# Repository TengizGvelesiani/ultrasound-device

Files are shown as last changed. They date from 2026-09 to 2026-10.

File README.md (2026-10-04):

# Portable Ultrasound System PCB

An open-source hardware and firmware project for a portable ultrasound system. This repository contains the schematic designs, PCB layouts, and FPGA-based digital signal processing infrastructure required to drive ultrasonic transducers, receive echoes, and process the resulting data.

## System Architecture

The architecture is divided into three main domains: the analog high-voltage front end, the FPGA-based digital signal processor (DSP), and the Python-based visualization software.

### Hardware & Analog Front End (AFE)
* **High-Voltage Pulser:** A high-voltage pulser circuit utilizing an **MD1213** high-speed dual-MOSFET driver paired with a **TC6320** complementary MOSFET pair. The FPGA generates highly precise transmit bursts (e.g., 3-cycle 5 MHz bursts) to ring the ultrasonic transducer.
* **Variable Gain Amplifier:** Features an **AD8331** Variable Gain Amplifier (VGA) optimized for ultrasound applications. The gain is dynamically driven by a hardware Time Gain Compensation (TGC) ramp using an **MCP4821** DAC to compensate for exponential acoustic attenuation in tissue.
* **Data Acquisition:** An **AD9226** Analog-to-Digital Converter (ADC) captures the amplified high-frequency RF signals at 20 MSPS.

### FPGA Digital Signal Processing (DSP)
The FPGA manages microsecond-precise transmit-receive (T/R) switching and processes the incoming 20 MHz data stream in real-time:
* **DC Blocking:** An Exponentially Weighted Moving Average (EWMA) high-pass filter actively tracks and rejects the ADC baseline DC offset.
* **Quadrature Demodulation:** Multiplier-less $f_s/4$ mixing (`[1, 0, -1, 0]`) brings the 5 MHz carrier frequency down to baseband.
* **Filtering & Magnitude:** FIR filters smooth the separated I and Q channels, and a hardware CORDIC calculates the exact signal magnitude ($\sqrt{I^2 + Q^2}$).
* **Log Compression:** To map the massive acoustic dynamic range to a visible spectrum, a BRAM-based Look-Up Table applies logarithmic compression before decimation.

### Software Stack & Visualization
* **High-Speed Telemetry:** The compressed ultrasound envelope is streamed over a 2,000,000 baud binary UART interface.
* **Python GUI:** A custom Python application reconstructs the data into a real-time medical-grade B-Scan waterfall using a `bone` colormap. The software applies customizable noise squelch (`NOISE_REJECT`) and contrast gain for optimal imaging of various targets.

## Repository Structure

* `/Pulser_PCB/` - Altium Designer project files (`.PrjPcb`), schematics (`.SchDoc`), and PCB layouts (`.PcbDoc`).
* `/FPGA/` - Vivado project and VHDL/Verilog source code for the FPGA, including the pulse controller and DSP pipelines.

## Getting Started

### Prerequisites
* **Altium Designer** for viewing, editing, and generating manufacturing files from the hardware project.
* **Xilinx Vivado (2018.3 or newer)** for synthesizing the digital logic.

### Viewing the Design
1. Clone this repository: `git clone https://github.com/TengizGvelesiani/ultrasound-device.git`
2. Open the hardware project file located in the `/Pulser_PCB/` directory using Altium Designer.
3. The top-level schematic outlines the power distribution, high-voltage pulser, and analog receive chain.

## Current Status & Roadmap

* [x] Initial schematic capture (Pulser, VGA, ADC)
* [x] PCB layout and routing
* [x] Board bring-up and power sequence testing
* [x] FPGA pulse generation and T/R switch timing verification (tuned for 5 MHz resonance)
* [x] Echo acquisition and DSP filtering (stable decimation, FIR, CORDIC)
* [x] Software visualization and UART pipeline integration
* [ ] Mechanical scanning and full 2D B-Scan implementation

## Disclaimer

**Educational and experimental purposes only.** This hardware generates high voltages and is not an approved medical device. It has not been evaluated by the FDA or any other regulatory body. Do not use this device on human subjects. The creators and contributors are not responsible for any damage, injury, or liability resulting from the use or misuse of this design. 

## License

This project is licensed under the [MIT License](LICENSE) - see the LICENSE file for details.

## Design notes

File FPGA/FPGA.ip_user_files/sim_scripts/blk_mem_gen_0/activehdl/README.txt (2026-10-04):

################################################################################
# Vivado (TM) v2018.3 (64-bit)
#
# README.txt: Please read the sections below to understand the steps required to
#             run the exported script and information about the source files.
#
# Generated by export_simulation on Sun Oct 04 17:19:32 +0400 2026
#
################################################################################

1. How to run the generated simulation script:-

From the shell prompt in the current directory, issue the following command:-

./blk_mem_gen_0.sh

This command will launch the 'compile', 'elaborate' and 'simulate' functions
implemented in the script file for the 3-step flow. These functions are called
from the main 'run' function in the script file.

The 'run' function first executes the 'setup' function, the purpose of which is to
create simulator specific setup files, create design library mappings and library
directories and copy 'glbl.v' from the Vivado software install location into the
current directory.

The 'setup' function is also used for removing the simulator generated data in
order to reset the current directory to the original state when export_simulation
was launched from Vivado. This generated data can be removed by specifying the
'-reset_run' switch to the './blk_mem_gen_0.sh' script.

./blk_mem_gen_0.sh -reset_run

To keep the generated data from the previous run but regenerate the setup files and
library directories, use the '-noclean_files' switch.

./blk_mem_gen_0.sh -noclean_files

For more information on the script, please type './blk_mem_gen_0.sh -help'.

2. Additional design information files:-

export_simulation generates following additional file that can be used for fetching
the design files information or for integrating with external custom scripts.

Name   : file_info.txt
Purpose: This file contains detail design file information based on the compile order
         when export_simulation was executed from Vivado. The file contains information
         about the file type, name, whether it is part of the IP, associated library
         and the file path information.

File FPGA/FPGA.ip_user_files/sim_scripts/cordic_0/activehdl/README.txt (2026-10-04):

################################################################################
# Vivado (TM) v2018.3 (64-bit)
#
# README.txt: Please read the sections below to understand the steps required to
#             run the exported script and information about the source files.
#
# Generated by export_simulation on Sun Oct 04 15:36:34 +0400 2026
#
################################################################################

1. How to run the generated simulation script:-

From the shell prompt in the current directory, issue the following command:-

./cordic_0.sh

This command will launch the 'compile', 'elaborate' and 'simulate' functions
implemented in the script file for the 3-step flow. These functions are called
from the main 'run' function in the script file.

The 'run' function first executes the 'setup' function, the purpose of which is to
create simulator specific setup files, create design library mappings and library
directories and copy 'glbl.v' from the Vivado software install location into the
current directory.

The 'setup' function is also used for removing the simulator generated data in
order to reset the current directory to the original state when export_simulation
was launched from Vivado. This generated data can be removed by specifying the
'-reset_run' switch to the './cordic_0.sh' script.

./cordic_0.sh -reset_run

To keep the generated data from the previous run but regenerate the setup files and
library directories, use the '-noclean_files' switch.

./cordic_0.sh -noclean_files

For more information on the script, please type './cordic_0.sh -help'.

2. Additional design information files:-

export_simulation generates following additional file that can be used for fetching
the design files information or for integrating with external custom scripts.

Name   : file_info.txt
Purpose: This file contains detail design file information based on the compile order
         when export_simulation was executed from Vivado. The file contains information
         about the file type, name, whether it is part of the IP, associated library
         and the file path information.

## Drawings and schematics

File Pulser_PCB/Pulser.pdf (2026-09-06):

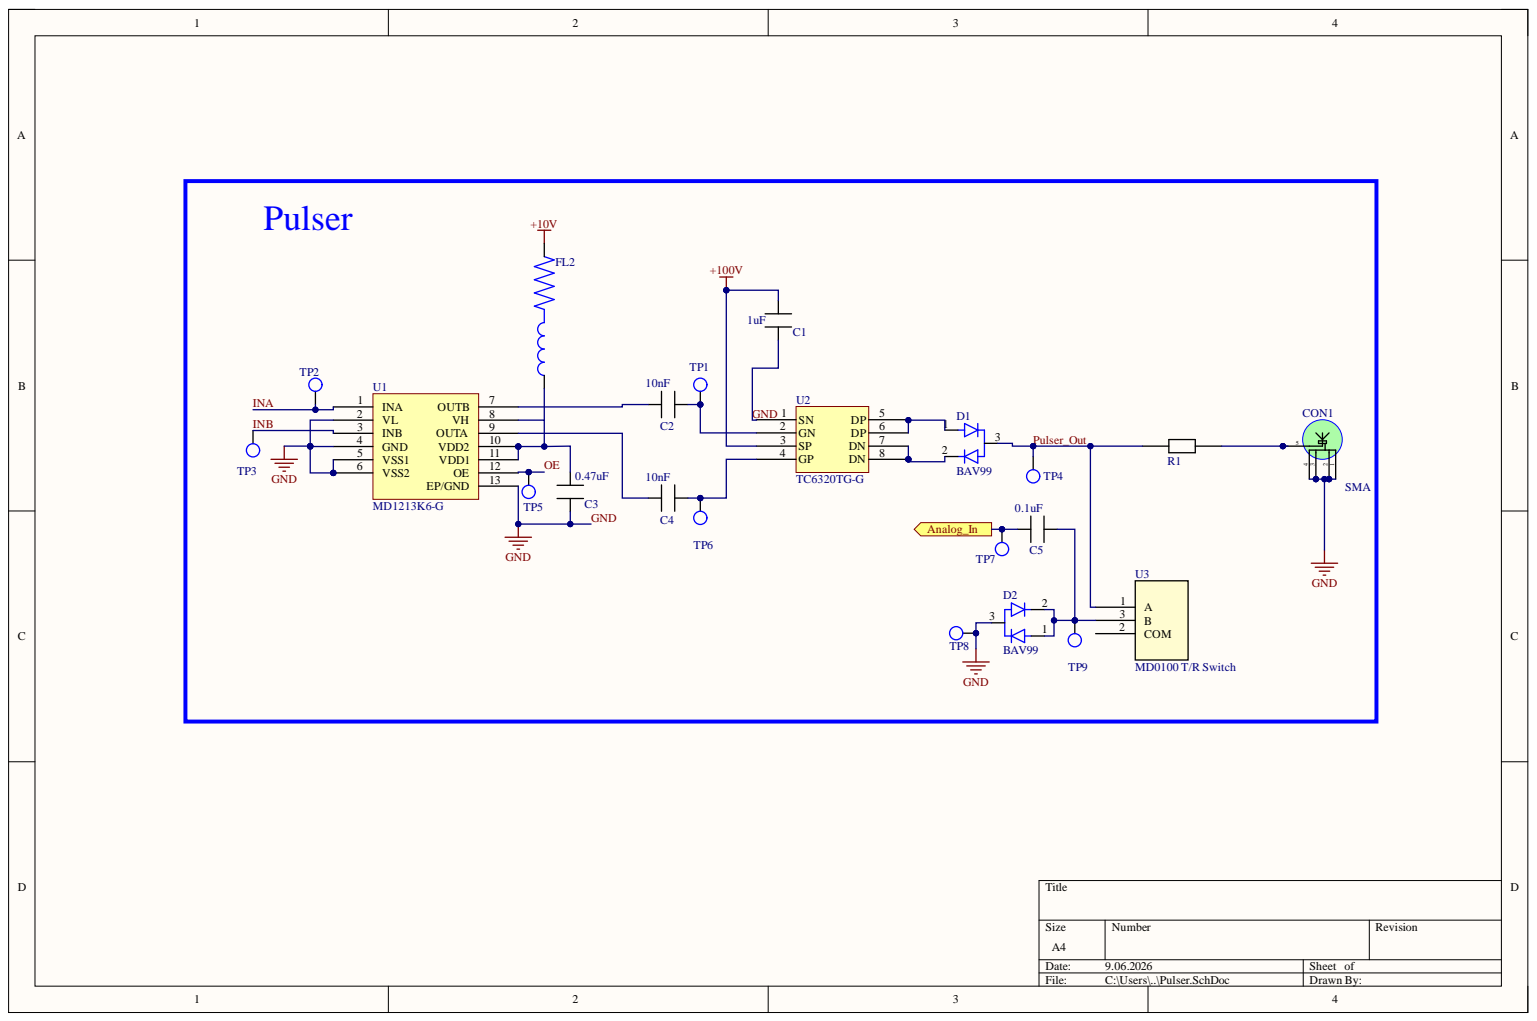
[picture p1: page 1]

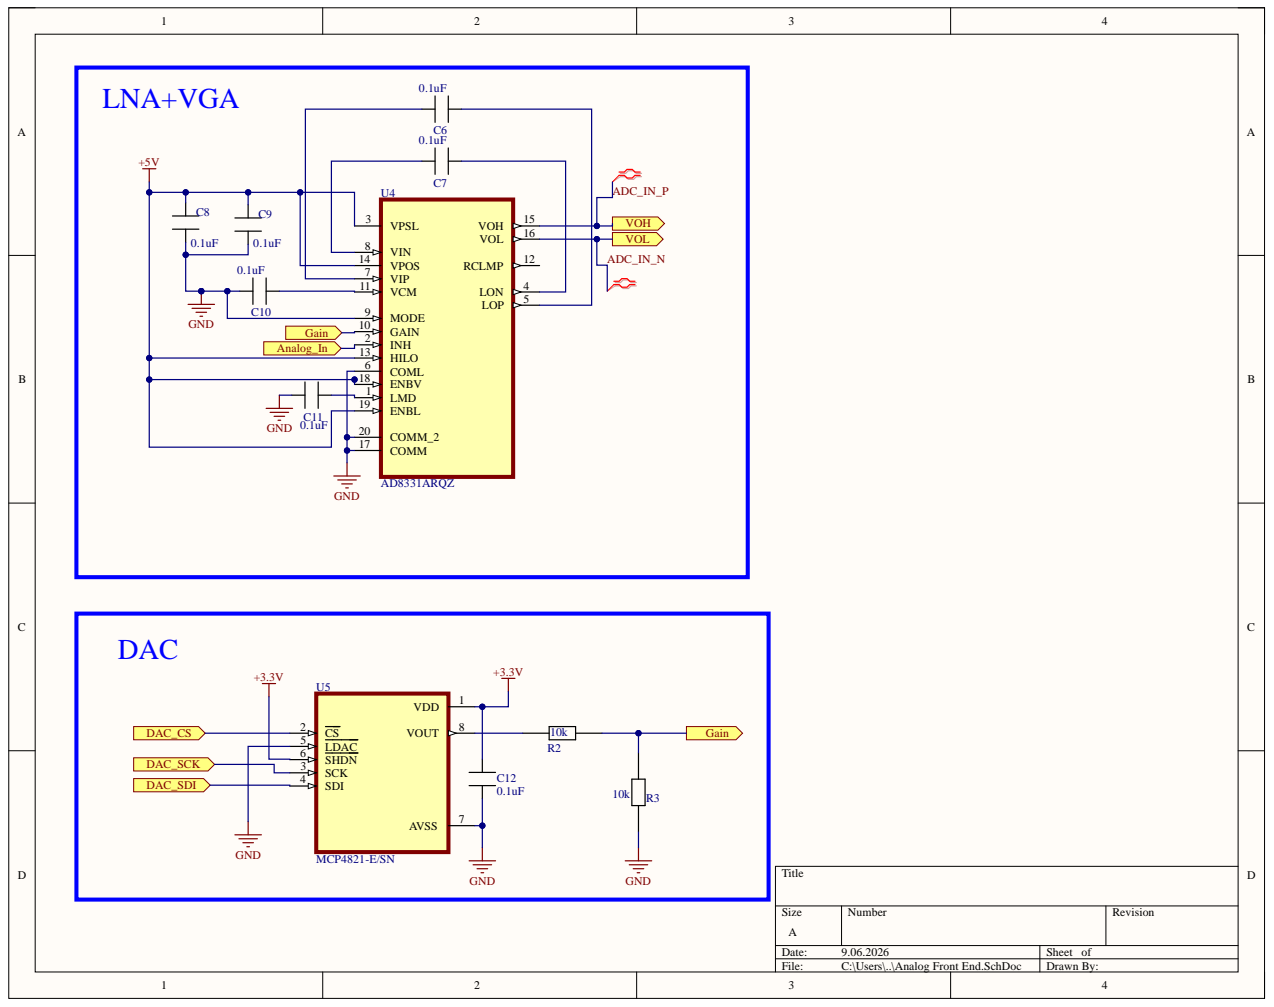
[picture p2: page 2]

ENBV 18

ENBL 19

SHDN 6

SDI 4

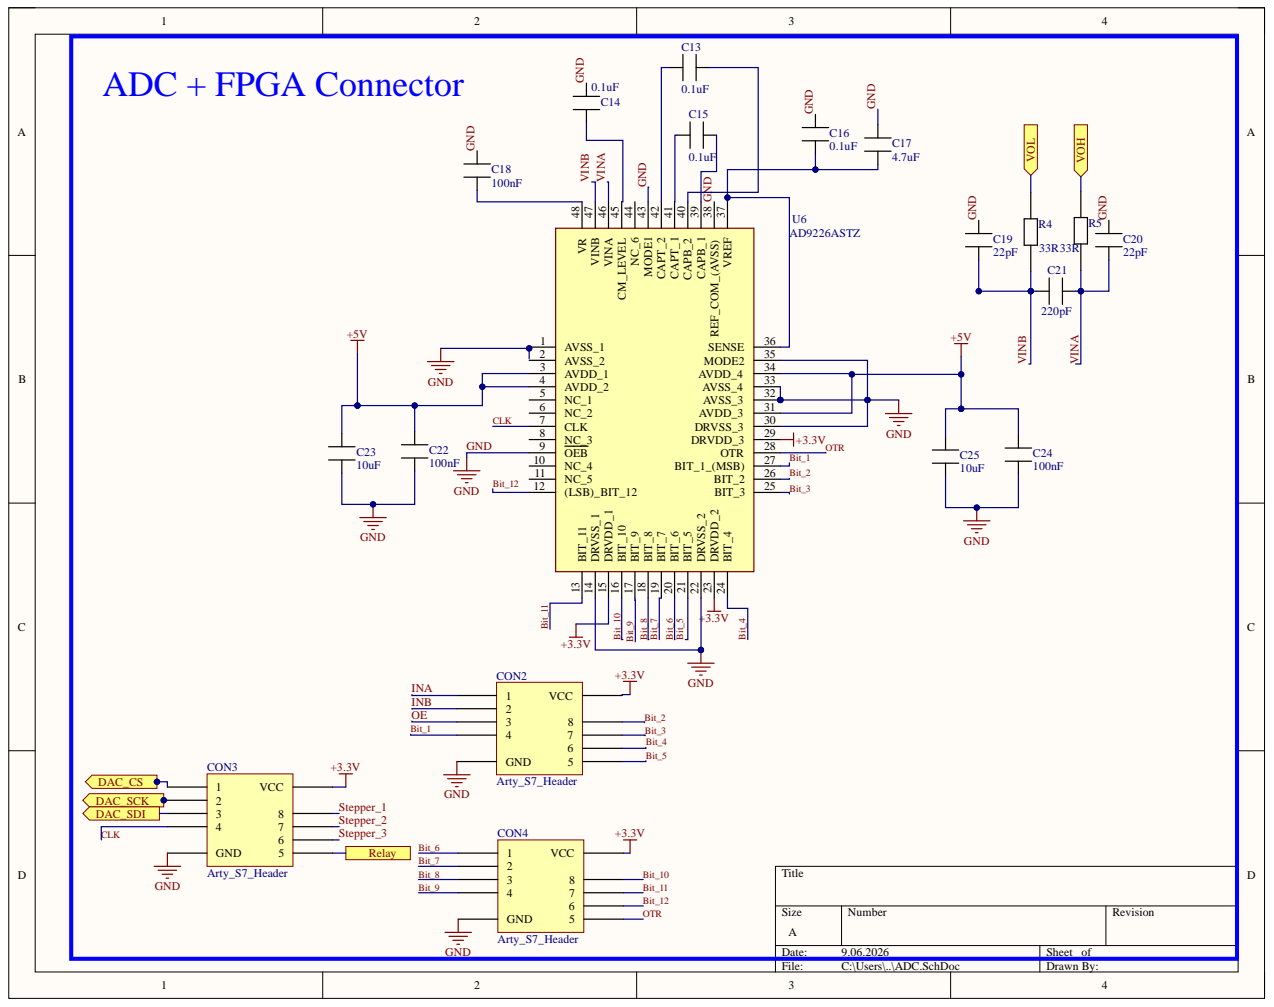
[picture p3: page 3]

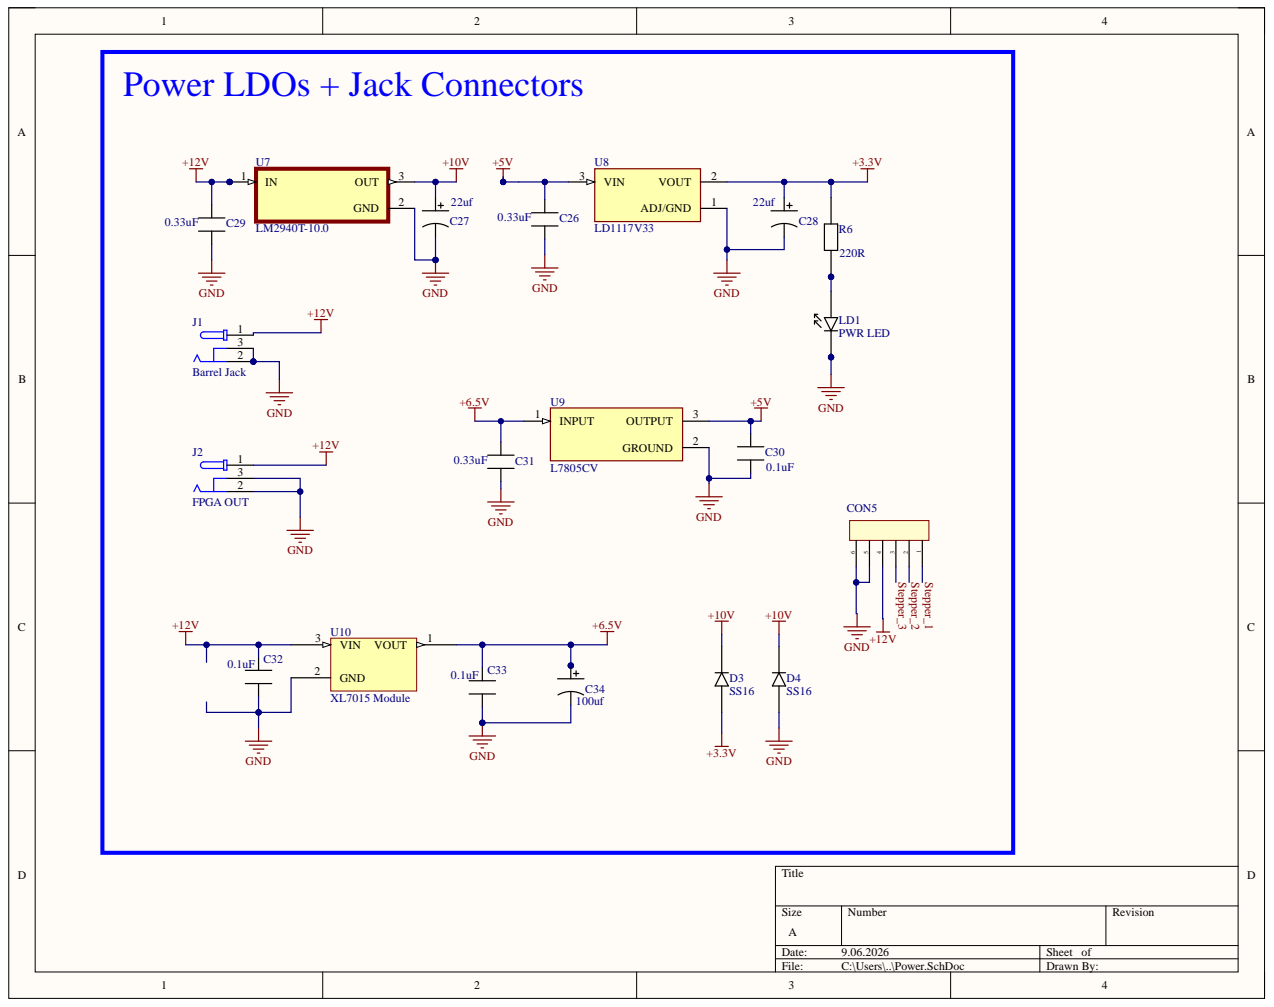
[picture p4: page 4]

Power LDOs + Jack Connectors

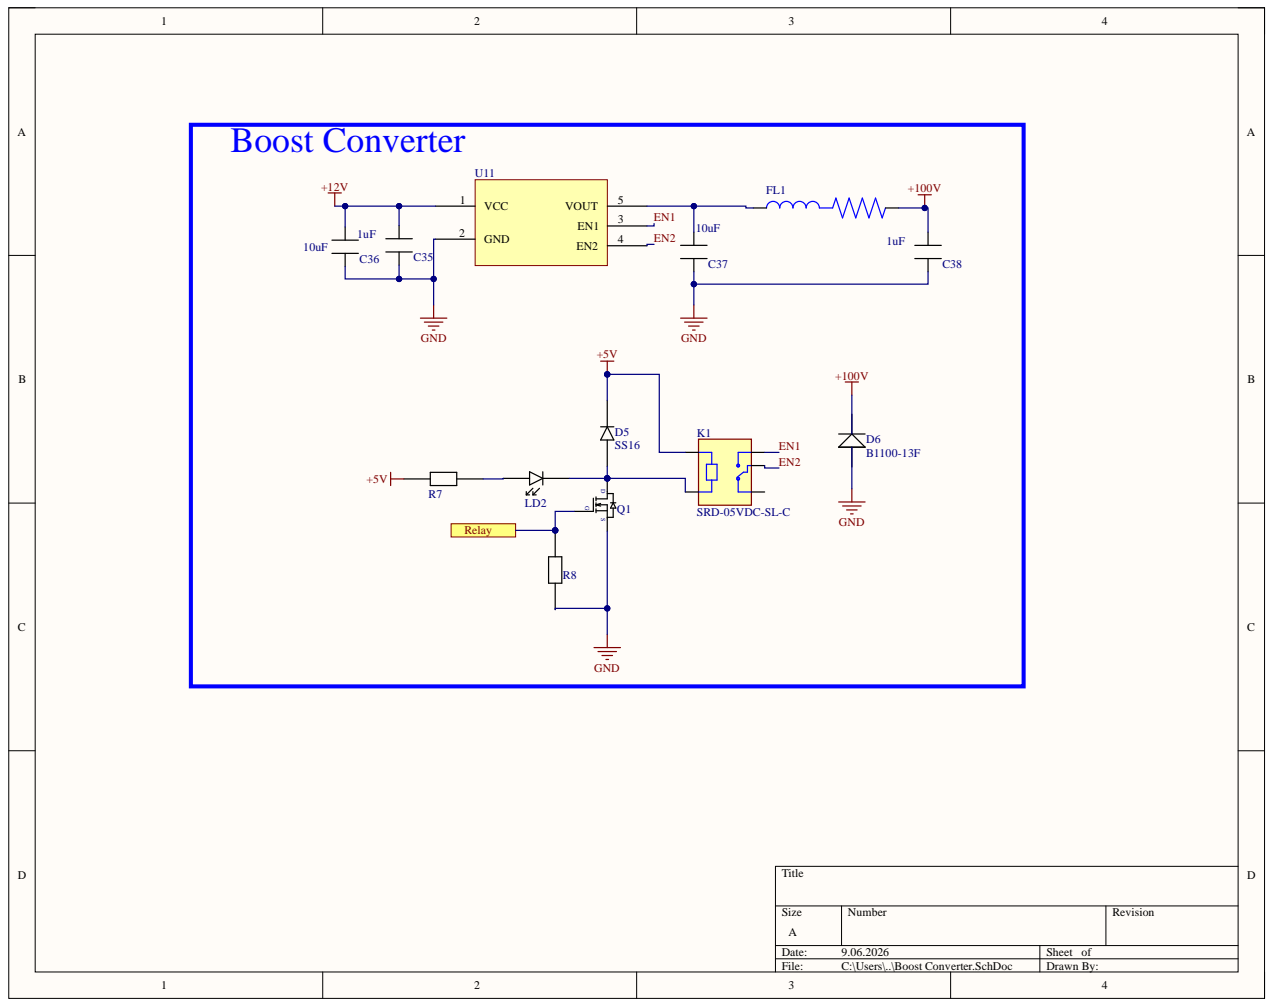
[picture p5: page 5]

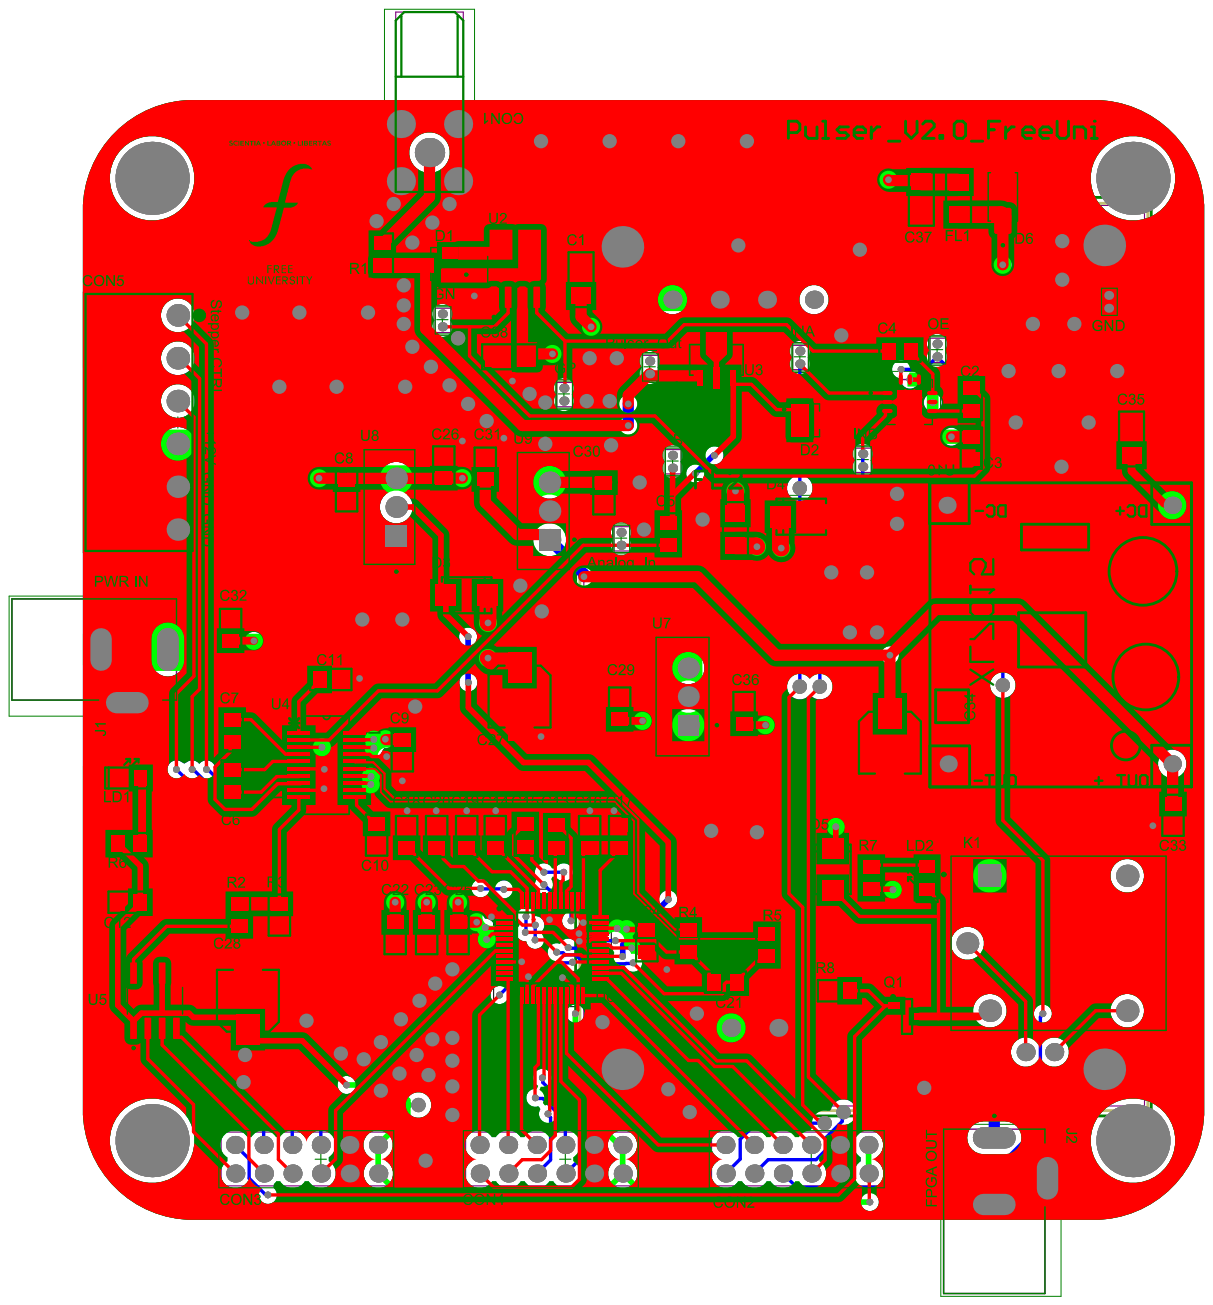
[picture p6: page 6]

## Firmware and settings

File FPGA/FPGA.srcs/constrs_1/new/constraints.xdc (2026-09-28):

## This file is a general .xdc for the Arty-S7 Rev. C
## To use it in a project:
## - uncomment the lines corresponding to used pins
## - rename the used ports (in each line, after get_ports) according to the top level signal names in the project

## Clock signal
#set_property -dict { PACKAGE_PIN F14   IOSTANDARD LVCMOS33 } [get_ports { CLK12MHZ }]; #IO_L13P_T2_MRCC_15 Sch=uclk
#create_clock -add -name sys_clk_pin -period 83.333 -waveform {0 41.667} [get_ports { CLK12MHZ }];
set_property -dict {PACKAGE_PIN R2 IOSTANDARD SSTL135} [get_ports CLK100MHZ]
create_clock -period 10.000 -name sys_clk_pin -waveform {0.000 5.000} -add [get_ports CLK100MHZ]

## Switches
#set_property -dict { PACKAGE_PIN H14   IOSTANDARD LVCMOS33 } [get_ports { sw[0] }]; #IO_L20N_T3_A19_15 Sch=sw[0]
#set_property -dict { PACKAGE_PIN H18   IOSTANDARD LVCMOS33 } [get_ports { sw[1] }]; #IO_L21P_T3_DQS_15 Sch=sw[1]
#set_property -dict { PACKAGE_PIN G18   IOSTANDARD LVCMOS33 } [get_ports { sw[2] }]; #IO_L21N_T3_DQS_A18_15 Sch=sw[2]
#set_property -dict { PACKAGE_PIN M5    IOSTANDARD SSTL135 } [get_ports { sw[3] }]; #IO_L6N_T0_VREF_34 Sch=sw[3]


## RGB LEDs
set_property -dict {PACKAGE_PIN J15 IOSTANDARD LVCMOS33} [get_ports {rgb_led[0]}]
set_property -dict {PACKAGE_PIN G17 IOSTANDARD LVCMOS33} [get_ports {rgb_led[1]}]
set_property -dict {PACKAGE_PIN F15 IOSTANDARD LVCMOS33} [get_ports {rgb_led[2]}]
set_property -dict {PACKAGE_PIN E15 IOSTANDARD LVCMOS33} [get_ports {rgb_led[3]}]
set_property -dict {PACKAGE_PIN F18 IOSTANDARD LVCMOS33} [get_ports {rgb_led[4]}]
set_property -dict {PACKAGE_PIN E14 IOSTANDARD LVCMOS33} [get_ports {rgb_led[5]}]


## LEDs
#set_property -dict { PACKAGE_PIN E18   IOSTANDARD LVCMOS33 } [get_ports { led[2] }]; #IO_L16N_T2_A27_15 Sch=led[2]
#set_property -dict { PACKAGE_PIN F13   IOSTANDARD LVCMOS33 } [get_ports { led[3] }]; #IO_L17P_T2_A26_15 Sch=led[3]
#set_property -dict { PACKAGE_PIN E13   IOSTANDARD LVCMOS33 } [get_ports { led[4] }]; #IO_L17N_T2_A25_15 Sch=led[4]
#set_property -dict { PACKAGE_PIN H15   IOSTANDARD LVCMOS33 } [get_ports { led[5] }]; #IO_L18P_T2_A24_15 Sch=led[5]


## Buttons
#set_property -dict { PACKAGE_PIN G15   IOSTANDARD LVCMOS33 } [get_ports { btn[0] }]; #IO_L18N_T2_A23_15 Sch=btn[0]
#set_property -dict { PACKAGE_PIN K16   IOSTANDARD LVCMOS33 } [get_ports { btn[1] }]; #IO_L19P_T3_A22_15 Sch=btn[1]
#set_property -dict { PACKAGE_PIN J16   IOSTANDARD LVCMOS33 } [get_ports { btn[2] }]; #IO_L19N_T3_A21_VREF_15 Sch=btn[2]
#set_property -dict { PACKAGE_PIN H13   IOSTANDARD LVCMOS33 } [get_ports { btn[3] }]; #IO_L20P_T3_A20_15 Sch=btn[3]


## PMOD Header JA (Relay, Stepper, DAC / ADC Clock)
set_property -dict { PACKAGE_PIN L17   IOSTANDARD LVCMOS33 } [get_ports { relay }];    # JA 1 (Pmod Pin 1)  - Relay
#set_property -dict { PACKAGE_PIN L18   IOSTANDARD LVCMOS33 } [get_ports { stepper3 }]; # JA 2 (Pmod Pin 2)  - Stepper3
#set_property -dict { PACKAGE_PIN M14   IOSTANDARD LVCMOS33 } [get_ports { stepper2 }]; # JA 3 (Pmod Pin 3)  - Stepper2
#set_property -dict { PACKAGE_PIN N14   IOSTANDARD LVCMOS33 } [get_ports { stepper1 }]; # JA 4 (Pmod Pin 4)  - Stepper1
set_property -dict { PACKAGE_PIN M16   IOSTANDARD LVCMOS33 } [get_ports { cs }];       # JA 5 (Pmod Pin 7)  - DAC_CS
set_property -dict { PACKAGE_PIN M17   IOSTANDARD LVCMOS33 } [get_ports { sck }];      # JA 6 (Pmod Pin 8)  - DAC_SCK
set_property -dict { PACKAGE_PIN M18   IOSTANDARD LVCMOS33 } [get_ports { sci }];      # JA 7 (Pmod Pin 9)  - DAC_SDI
set_property -dict { PACKAGE_PIN N18   IOSTANDARD LVCMOS33 } [get_ports { clk }];      # JA 8 (Pmod Pin 10) - ADC_CLK


## PMOD Header JB (OTR & Parallel ADC Upper Bits)
set_property -dict { PACKAGE_PIN P17   IOSTANDARD LVCMOS33 } [get_ports { otr }];          # JB 1 (Pmod Pin 1)  - OTR
set_property -dict { PACKAGE_PIN P18   IOSTANDARD LVCMOS33 } [get_ports { adc_data[12] }]; # JB 2 (Pmod Pin 2)  - ADC_BIT12
set_property -dict { PACKAGE_PIN R18   IOSTANDARD LVCMOS33 } [get_ports { adc_data[11] }]; # JB 3 (Pmod Pin 3)  - ADC_BIT11
set_property -dict { PACKAGE_PIN T18   IOSTANDARD LVCMOS33 } [get_ports { adc_data[10] }]; # JB 4 (Pmod Pin 4)  - ADC_BIT10
set_property -dict { PACKAGE_PIN P14   IOSTANDARD LVCMOS33 } [get_ports { adc_data[6] }];  # JB 5 (Pmod Pin 7)  - ADC_BIT6
set_property -dict { PACKAGE_PIN P15   IOSTANDARD LVCMOS33 } [get_ports { adc_data[7] }];  # JB 6 (Pmod Pin 8)  - ADC_BIT7
set_property -dict { PACKAGE_PIN N15   IOSTANDARD LVCMOS33 } [get_ports { adc_data[8] }];  # JB 7 (Pmod Pin 9)  - ADC_BIT8
set_property -dict { PACKAGE_PIN P16   IOSTANDARD LVCMOS33 } [get_ports { adc_data[9] }];  # JB 8 (Pmod Pin 10) - ADC_BIT9
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

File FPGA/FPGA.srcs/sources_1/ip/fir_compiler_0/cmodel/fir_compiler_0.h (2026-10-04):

//------------------------------------------------------------------------------
// (c) Copyright 2014 Xilinx, Inc. All rights reserved.
//
// This file contains confidential and proprietary information
// of Xilinx, Inc. and is protected under U.S. and
// international copyright and other intellectual property
// laws.
//
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
// CRITICAL APPLICATIONS
// Xilinx products are not designed or intended to be fail-
// safe, or for use in any application requiring fail-safe
// performance, such as life-support or safety devices or
// systems, Class III medical devices, nuclear facilities,
// applications related to the deployment of airbags, or any
// other applications that could lead to death, personal
// injury, or severe property or environmental damage
// (individually and collectively, "Critical
// Applications"). Customer assumes the sole risk and
// liability of any use of Xilinx products in Critical
// Applications, subject only to applicable laws and
// regulations governing limitations on product liability.
//
// THIS COPYRIGHT NOTICE AND DISCLAIMER MUST BE RETAINED AS
// PART OF THIS FILE AT ALL TIMES.
//------------------------------------------------------------------------------ 
//
// C Model configuration for the "fir_compiler_0" instance.
//
//------------------------------------------------------------------------------
//
// coefficients: -14,-24,-20,7,56,114,163,189,189,163,114,56,7,-20,-24,-14
// chanpats: 173
// name: fir_compiler_0
// filter_type: 0
// rate_change: 0
// interp_rate: 1
// decim_rate: 1
// zero_pack_factor: 1
// coeff_padding: 0
// num_coeffs: 16
// coeff_sets: 1
// reloadable: 0
// is_halfband: 0
// quantization: 0
// coeff_width: 16
// coeff_fract_width: 0
// chan_seq: 0
// num_channels: 1
// num_paths: 1
// data_width: 16
// data_fract_width: 0
// output_rounding_mode: 1
// output_width: 24
// output_fract_width: 0
// config_method: 0

const double fir_compiler_0_coefficients[16] = {-14,-24,-20,7,56,114,163,189,189,163,114,56,7,-20,-24,-14};

const xip_fir_v7_2_pattern fir_compiler_0_chanpats[1] = {P_BASIC};

static xip_fir_v7_2_config gen_fir_compiler_0_config() {
  xip_fir_v7_2_config config;
  config.name                = "fir_compiler_0";
  config.filter_type         = 0;
  config.rate_change         = XIP_FIR_INTEGER_RATE;
  config.interp_rate         = 1;
  config.decim_rate          = 1;
  config.zero_pack_factor    = 1;
  config.coeff               = &fir_compiler_0_coefficients[0];
  config.coeff_padding       = 0;
  config.num_coeffs          = 16;
  config.coeff_sets          = 1;
  config.reloadable          = 0;
  config.is_halfband         = 0;
  config.quantization        = XIP_FIR_INTEGER_COEFF;
  config.coeff_width         = 16;
  config.coeff_fract_width   = 0;
  config.chan_seq            = XIP_FIR_BASIC_CHAN_SEQ;
  config.num_channels        = 1;
  config.init_pattern        = fir_compiler_0_chanpats[0];
  config.num_paths           = 1;
  config.data_width          = 16;
  config.data_fract_width    = 0;
  config.output_rounding_mode= XIP_FIR_TRUNCATE_LSBS;
  config.output_width        = 24;
  config.output_fract_width  = 0,
  config.config_method       = XIP_FIR_CONFIG_SINGLE;
  return config;
}

const xip_fir_v7_2_config fir_compiler_0_config = gen_fir_compiler_0_config();

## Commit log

2026-03-17 pulser circuit finished
    [IC_Digital.PcbLib, IC_Digital.SchLib, MD1213K6-G.SchLib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]
2026-03-27 added schematics
    [ADC.SchDoc, Analog Front End.SchDoc, Connectors.PcbLib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]
2026-03-28 added power plug
    [Connectors.PcbLib, Connectors.SchLib, Power.SchDoc]
2026-03-28 add power schematics
    [ADC.SchDoc, Analog Front End.SchDoc, IC_Power.PcbLib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]
2026-03-29 changed bnc to sma connector
    [ADC.SchDoc, Analog Front End.SchDoc, Power.SchDoc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]
2026-03-30 first draft pcb layout
    [ADC.SchDoc, Analog Front End.SchDoc, Boost Converter.SchDoc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]
2026-03-30 updated gitignore
    [Pulser.PrjPcb]
2026-03-30 updated size
    [Boost Converter.SchDoc, IC_Power.PcbLib, Pulser.PcbDoc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]
2026-03-31 started routing
    [ADC.SchDoc, Analog Front End.SchDoc, Boost Converter.SchDoc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]
2026-03-31 finished pcb
    [Pulser.PcbDoc, Pulser.PrjPcb]
2026-03-31 finish pcb
    [Pulser.PrjPcb]
2026-03-31 change capacitor footprints
    [Boost Converter.SchDoc, Power.SchDoc, Pulser.PcbDoc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]
2026-04-01 final version
    [ADC.SchDoc, Boost Converter.SchDoc, Connectors.PcbLib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]
2026-09-04 updated connectors diodes
    [ADC.SchDoc, Boost Converter.SchDoc, Connectors.PcbLib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]
2026-09-04 add testpoints
    [ADC.SchDoc, Analog Front End.SchDoc, Boost Converter.SchDoc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]
2026-09-04 add test points
    [Pulser.SchDoc]
2026-09-04 small bug fix
    [ADC.SchDoc, Analog Front End.SchDoc, Boost Converter.SchDoc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]
2026-09-04 updated pcb layout
    [Boost Converter.SchDoc, Connectors.PcbLib, IC_Power.PcbLib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]
2026-09-06 finished v2.0
    [ADC.SchDoc, Boost Converter.SchDoc, Power.SchDoc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]
2026-09-06 v2.0 minor fixes
    [Pulser.PcbDoc]
2026-09-28 Downgrade FPGA project to Vivado 2018.3 and clean up gitignore
    [Pulser.PcbDoc]
2026-09-28 docs: Update README to reflect current project structure
2026-11-04 implemented stepper control
